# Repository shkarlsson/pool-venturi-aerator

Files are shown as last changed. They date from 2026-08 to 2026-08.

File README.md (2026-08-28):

# Parametric In-Line Venturi Pool Aerator





A fully parametric, hydraulic in-line Venturi aerator for above-ground pool return lines (Bestway, Intex, etc.). Spliced externally into the return hose between the pump/sand filter and the pool inlet. 

It uses the Venturi effect to create a localized low-pressure zone at the constricted throat, drawing ambient air through a snorkel tube and injecting micro-bubbles into the pool to raise pH, cool water in hot weather, and create a spa jet stream without external air pumps.

> 🌐 **Interactive 3D Preview:** View and inspect the model in 3D directly on GitHub: **[models/pool_venturi_aerator_default.stl](models/pool_venturi_aerator_default.stl)**

---

## ⚖️ Licensing & Open Source Terms

* **Upstream CAD Source (`.scad`, Python tests):** Licensed under **[CERN-OHL-S v2 (Strongly Reciprocal)](LICENSE)**. If you modify or distribute physical prints manufactured from this source, you must make your modified source files available under the same license.
* **Platform Mesh Exports (`.stl`, `.3mf` on Printables/MakerWorld):** Distributed under **CC-BY-SA 4.0** for platform compatibility.

---

## 📐 Pre-Compiled Release Matrix

The automated CI pipeline compiles and verifies 12 standard size combinations ($2 \times 2 \times 3$ matrix):

| Variant File | Pool Hose ID | Air Tube ID | Pump Flow Rating | Throat ID |
| :--- | :--- | :--- | :--- | :--- |
| `aerator_32mm_air6mm_pumpSmall.stl` | **32 mm** (1.25") | **6 mm** | Small (<3.0 m³/h / <800 GPH) | 12.0 mm |
| `aerator_32mm_air6mm_pumpMed.stl` | **32 mm** (1.25") | **6 mm** | Med (3.0–6.0 m³/h / Sand) | 14.0 mm |
| `aerator_32mm_air6mm_pumpLarge.stl` | **32 mm** (1.25") | **6 mm** | Large (>6.0 m³/h / >1500 GPH) | 16.0 mm |
| `aerator_32mm_air8mm_pumpSmall.stl` | **32 mm** (1.25") | **8 mm** | Small (<3.0 m³/h) | 12.0 mm |
| `aerator_32mm_air8mm_pumpMed.stl` | **32 mm** (1.25") | **8 mm** | Med (3.0–6.0 m³/h / Sand) | 14.0 mm |
| `aerator_32mm_air8mm_pumpLarge.stl` | **32 mm** (1.25") | **8 mm** | Large (>6.0 m³/h) | 16.0 mm |
| `aerator_38mm_air6mm_pumpSmall.stl` | **38 mm** (1.50") | **6 mm** | Small (<3.0 m³/h) | 14.0 mm |
| `aerator_38mm_air6mm_pumpMed.stl` | **38 mm** (1.50") | **6 mm** | Med (3.0–6.0 m³/h / Sand) | 16.0 mm |
| `aerator_38mm_air6mm_pumpLarge.stl` | **38 mm** (1.50") | **6 mm** | Large (>6.0 m³/h) | 18.0 mm |
| `aerator_38mm_air8mm_pumpSmall.stl` | **38 mm** (1.50") | **8 mm** | Small (<3.0 m³/h) | 14.0 mm |
| `aerator_38mm_air8mm_pumpMed.stl` | **38 mm** (1.50") | **8 mm** | Med (3.0–6.0 m³/h / Sand) | 16.0 mm |
| `aerator_38mm_air8mm_pumpLarge.stl` | **38 mm** (1.50") | **8 mm** | Large (>6.0 m³/h) | 18.0 mm |

---

## 🖨️ Recommended Print Settings

* **Filament:** **PETG** or **ASA** (Chlorine, water pressure, and UV resistance are mandatory; do not use PLA).
* **Orientation:** Print vertically standing on the **inlet hose barb** ($Z=0$).
* **Supports:** **None needed.** The tilted downstream air intake and the 45° double-taper hose retention ridges are 100% self-supporting when standing vertically.
* **Perimeters / Walls:** Set to **5–6 walls** (or 100% infill) so the part is solid and completely watertight under backpressure.
* **Layer Height:** 0.20 mm.

---

## 🔧 Installation & Plumbing Instructions

1. **Direction of Flow:** Water must enter through the short inlet barb, pass through the converging nozzle, pass the air suction orifice, and exit through the longer outlet/spacer barb toward the pool return inlet.
2. **Snorkel / Anti-Siphon Tube Height (CRITICAL):**
   * Connect a flexible hose / tube (garden hose or 6/8mm silicone tubing) to the barbed air intake nipple.
   * Secure it with a small hose clamp or zip-tie.
   * **Route the open end of the air tube well ABOVE the maximum pool water level** (e.g. zip-tied to a top pool rail or fence post).
   * ⚠️ *Why?* When the pool pump turns off, water pressure drops and pool water can backflow out of the air nipple by gravity. Keeping the tube opening above the pool water line acts as an air siphon break, preventing pool draining / water leaks onto your equipment pad.
3. **Flow Tuning / Air Control (Optional):** You can install a small inline valve or thumbscrew clamp on the air tube to dial between silent high-flow water jetting and maximum aeration / frothing.

---

## 🛠️ Customizing Parameters

Open `src/pool_venturi_aerator.scad` in OpenSCAD or use the Customizer pane:
* `mating_hose_id`: Inside diameter of your flexible pool hose.
* `air_tube_id`: Inside diameter of your silicone intake tube.
* `throat_id`: Constricted diameter (adjust based on pump velocity).

---

## 🧪 Automated Testing

To run the geometric validation test suite locally:

```bash
python3 tests/test_geometry.py
```

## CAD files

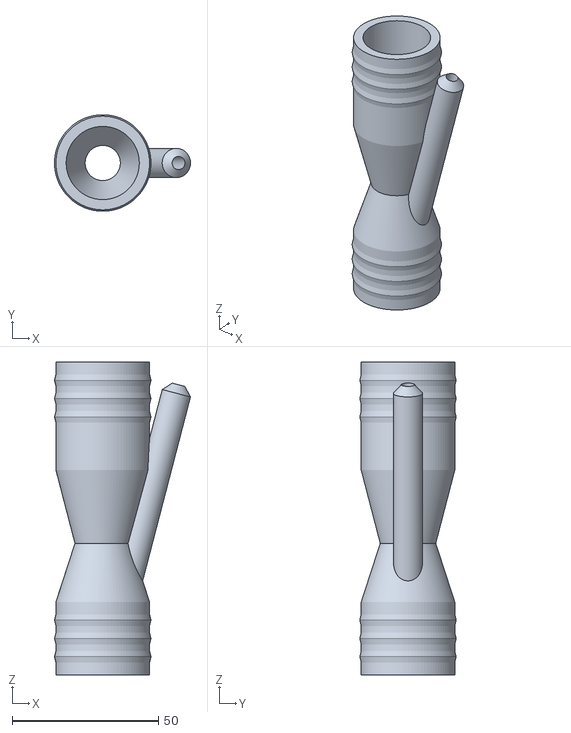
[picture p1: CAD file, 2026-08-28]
models/pool_venturi_aerator_default.stl
46.5 x 33.0 x 107.0

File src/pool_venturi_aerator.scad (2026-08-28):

// ====================================================================
// Parametric In-Line Venturi Pool Aerator (External Hose Mount)
// Upstream Source: https://github.com/shkarlsson/pool-venturi-aerator
// License: CERN-OHL-S v2 (Source) / CC-BY-SA 4.0 (Mesh Exports)
//
// Default orientation: Vertical standing on inlet hose barb (+Z).
// Tilted downstream air intake and 45° double-taper ridges require 0 supports.
// ====================================================================

$fn = 90;

// [Main Pool Hose Barb (Water In / Water Out)]
// Inside diameter of your flexible pool hose (e.g. 32mm / 1.25" or 38mm / 1.5")
mating_hose_id      = 32.0; 
// Wall thickness of the printed part (ensure 100% watertightness)
wall_thick          = 3.5;  
// Length of each hose barb end
barb_length         = 25.0; 
// Extra outer radius expansion on retention ridges
barb_ridge_extra    = 0.5;  

// [Hydraulic Venturi Core]
// Constricted venturi throat ID (accelerates water velocity to create vacuum)
// Recommended: 12-14mm for small pumps (<3m3/h), 14-16mm for medium (3-6m3/h), 18-20mm for large (>6m3/h)
throat_id           = 12.0; 
// Length of converging cone
converge_len        = 20.0; 
// Length of diverging expansion cone (diffuser)
diverge_len         = 25.0; 

// [Air Suction Intake Nipple]
// Inside diameter of your ambient air / silicone tube (nipple OD matches this)
air_tube_id         = 6.0;  
// Wall thickness of the air nipple
air_nipple_wall     = 2.0;  
// Height of the air intake stem
air_nipple_protrude = 22.0;
 
// [Inlet Barb Clearance Spacer]
// Smooth barb-less straight tube distance before barb starts (clears air tube clamp/access)
spacer_len          = 12.0; 

// [Bed Adhesion & Structural Support Ridge (Bottom)]
// Width of the flat contact foot on the build plate (stops cylindrical rolling/warping)
foot_width          = 5.0; 

// --- CALCULATED VALUES ---
air_nipple_height   = air_nipple_protrude + 31;
air_nipple_od       = air_tube_id + (2 * air_nipple_wall);
air_bore_id         = max(3.0, air_tube_id - 1.5);
main_id             = mating_hose_id - (2 * wall_thick);
total_length        = (2 * barb_length) + spacer_len + converge_len + diverge_len;
max_outer_r         = (mating_hose_id / 2) + barb_ridge_extra;

// --- MODULES ---

module hose_barb(od, len, wall) {
    id = od - (2 * wall);
    num_ridges = 3;
    ridge_spacing = len / (num_ridges + 1);
    ridge_h = 4.0;
    
    difference() {
        union() {
            // Main cylindrical barb body
            cylinder(r = od/2, h = len, center = false);
            // Symmetrical double-taper ridges (steep bidirectional taper, 100% printable standing without support)
            for (i = [1 : num_ridges]) {
                translate([0, 0, i * ridge_spacing - (ridge_h / 2)]) {
                    // Lower taper ramping up (45° angle)
                    cylinder(r1 = od/2, r2 = (od/2) + barb_ridge_extra, h = ridge_h / 2, center = false);
                    // Upper taper ramping down (45° angle)
                    translate([0, 0, ridge_h / 2])
                        cylinder(r1 = (od/2) + barb_ridge_extra, r2 = od/2, h = ridge_h / 2, center = false);
                }
            }
        }
        // Inner bore
        translate([0, 0, -1])
            cylinder(r = id/2, h = len + 2, center = false);
    }
}

module air_nipple_outer(base_r, stem_h, nipple_r) {
    tip_taper_len = 3.0;
    cyl_h = stem_h - tip_taper_len;
    
    // Main stem cylinder
    cylinder(r = nipple_r, h = base_r + cyl_h, center = false);
    // Tapered "tippy" lead-in cone at the top for easy tube sliding
    translate([0, 0, base_r + cyl_h])
        cylinder(r1 = nipple_r, r2 = (air_tube_id / 2) * 0.75, h = tip_taper_len, center = false);
}

module venturi_core() {
    inlet_ir  = main_id / 2;
    throat_ir = throat_id / 2;
    
    inlet_or  = mating_hose_id / 2;
    throat_or = throat_ir + wall_thick;
    
    // Angle of the diverging diffuser cone wall relative to the central Z axis
    // Matches the downstream expansion slope that the air intake stem runs alongside
    diverge_angle = atan2(inlet_or - throat_or, diverge_len);
    
    air_nipple_offset = (throat_or * cos(diverge_angle)) + (air_bore_id / 2);

    
    difference() {
        union() {
            // Converging outer cone
            cylinder(r1 = inlet_or, r2 = throat_or, h = converge_len, center = false);
            // Diverging outer cone
            translate([0, 0, converge_len])
                cylinder(r1 = throat_or, r2 = inlet_or, h = diverge_len, center = false);
            // Tapered air suction nipple tilted to match the diverging expansion cone slope
            // and pointing downstream towards the expansion chamber (+Z)
            translate([0, 0, converge_len])
                rotate([0, diverge_angle, 0])
                    translate([air_nipple_offset,0,-15])
                        air_nipple_outer(inlet_or, air_nipple_height + 5, air_nipple_od / 2);
        }
        
        // Internal Flow Path (The Venturi)
        // Entry & exit margins for clean CGAL manifold subtractions without altering boundary diameters
        conv_slope = (inlet_ir - throat_ir) / converge_len;
        div_slope  = (inlet_ir - throat_ir) / diverge_len;
        eps = 0.5;
        
        // 1. Converging cone
        translate([0, 0, -eps])
            cylinder(r1 = inlet_ir + (conv_slope * eps), r2 = throat_ir, h = converge_len + eps, center = false);
            
        // 2. Diverging expansion cone
        translate([0, 0, converge_len])
            cylinder(r1 = throat_ir, r2 = inlet_ir + (div_slope * eps), h = diverge_len + eps, center = false);
            
        // 3. Air suction hole drilled through the tilted nipple into the start of the expansion chamber
        translate([0, 0, converge_len])
            rotate([0, diverge_angle, 0])
                translate([air_nipple_offset,0,-20])
                    cylinder(r = air_bore_id / 2, h = inlet_or + air_nipple_height + 30, center = false);
    }
}



module straight_pipe(od, len, wall) {
    id = od - (2 * wall);
    difference() {
        cylinder(r = od/2, h = len, center = false);
        translate([0, 0, -1])
            cylinder(r = id/2, h = len + 2, center = false);
    }
}

// --- VERTICAL ASSEMBLY PRIMITIVE ---
module aerator() {
    // 1. Inlet Hose Barb
    hose_barb(mating_hose_id, barb_length, wall_thick);
        
    // 2. Venturi Core
    translate([0, 0, barb_length])
        venturi_core();
        
    // 3. Smooth barb-less straight spacer tube after the venturi core
    translate([0, 0, barb_length + converge_len + diverge_len])
        straight_pipe(mating_hose_id, spacer_len, wall_thick);
        
    // 4. Outlet Hose Barb
    translate([0, 0, barb_length + converge_len + diverge_len + spacer_len])
        hose_barb(mating_hose_id, barb_length, wall_thick);
}

// --- COMPLETE PRINT-READY ORIENTATION ---

// Render
aerator();

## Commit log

2026-08-28 Release v1.0.0: Parametric Pool Venturi Aerator (CERN-OHL-S v2)
    - OpenSCAD parametric model with 12-variant matrix
    - Headless geometry manifold tests
    - GitHub Actions CI/CD matrix build workflow
    [pool_venturi_aerator.scad]
2026-08-28 feat: vertical print orientation, tilted intake, 45deg double-taper ridges (v1.1.0)
    [pool_venturi_aerator.scad]
2026-08-28 docs: add default model STL for interactive GitHub 3D WebGL viewer
    [pool_venturi_aerator_default.stl]
2026-08-28 fix(cad): fix diffuser alignment, air nipple tangency, and bore transitions (v1.1.1)
    [pool_venturi_aerator.scad, pool_venturi_aerator_default.stl]
2026-08-28 fix(cad): align air bore inside wall tangent to outer cone wall
    [pool_venturi_aerator.scad, pool_venturi_aerator_default.stl]
2026-08-28 debug: set defaults to 32mm hose, 6mm air, 12mm throat (failing matrix config)
    [pool_venturi_aerator.scad, pool_venturi_aerator_default.stl]

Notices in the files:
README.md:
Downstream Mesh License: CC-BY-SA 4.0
